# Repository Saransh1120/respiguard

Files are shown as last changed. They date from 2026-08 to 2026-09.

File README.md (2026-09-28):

# RespiGuard

A chest-worn asthma monitor built around an ESP32-S3. It learns the wearer's own
baseline for oxygen saturation, breathing rate and heart rate, then flags an
episode when those drift away from that baseline while a wheeze classifier is
also firing. Movement suppresses the alert, so exertion is not mistaken for an
attack.

Hand-soldered from breakout modules. The core modules cost about ₹2,674, or
about ₹3,503 with the optional BME680. Battery, power parts, enclosure and
assembly are extra. The separate ₹1,707 order in the hardware handbook covers
those power parts, the enclosure and bench tools, not the sensor modules.

## Where things stand

| | |
|---|---|
| Parts | Ordered 27 Aug 2026, awaiting delivery |
| Simulation | Working — reaches ALERT, exertion veto demonstrated |
| Self-test firmware | Written, compiles, untested on hardware |
| Real firmware | Written, compiles, untested on hardware |
| Recorder firmware | Written, compiles, untested on hardware |
| Wheeze model | Trained on ICBHI. AUC 0.747 |
| Enclosure | Modelled, STLs rendered, not printed |

Nothing in this project has run on real hardware yet. Everything compiles and
the model's export is verified against the trained network, but that is the
extent of it.

## What is where

| Folder | What it holds |
|---|---|
| `RespiGuard_selftest/` | Probes every sensor over raw I²C, prints a pass/fail table. Run this first. |
| `RespiGuard_firmware/` | The real firmware — detection logic, sensor drivers, the classifier. |
| `RespiGuard_recorder/` | Streams mic audio over USB, for collecting fine-tuning data. |
| `simulation/` | The Wokwi sketch and circuit the detection logic was proven in. |
| `enclosure/` | Parametric case in OpenSCAD, plus rendered STLs. |
| `docs/BRINGUP_GUIDE.html` | The assembly and test procedure. Open in a browser at the bench. |

The machine-learning work and the build tools sit on `D:`, deliberately outside
this OneDrive folder — the dataset is 1.8 GB and should not be syncing.

| Path | What it holds |
|---|---|
| `D:\respiguard-ml\` | Training pipeline, virtual environment, runs, results |
| `D:\datasets\icbhi\` | The ICBHI 2017 respiratory sound database |
| `D:\tools\arduino-cli\` | Compiles sketches without opening the IDE |
| `D:\tools\openscad\` | Renders the enclosure STLs |

## The order things happen in

**Now, before parts arrive.** Nothing left. Firmware, model, enclosure and the
bring-up procedure are all written.

**When parts arrive.** Follow `docs/BRINGUP_GUIDE.html`. Power first and alone,
then one sensor at a time with the self-test after each, then the real firmware.

**After that.** Record 50–100 normal breaths on the finished device with
`record.py`, fine-tune the classifier on them, re-export and re-verify. This is
the step that closes the gap between ICBHI's stethoscope recordings and a
microphone under clothing, and it is not optional.

## Rebuilding the model from scratch

    cd D:\respiguard-ml
    .venv\Scripts\python.exe prepare_icbhi.py --src D:\datasets\icbhi\extracted
    .venv\Scripts\python.exe train_wheeze.py --epochs 200 --lr 5e-4
    .venv\Scripts\python.exe export_weights.py
    .venv\Scripts\python.exe verify_export.py

`verify_export.py` is not a formality. It is what proves the header the firmware
compiles in computes the same thing as the network whose score you are quoting.
Run it after every export.

## On the numbers

The classifier scores AUC 0.747 on patients it never trained on. Sensitivity is
0.885 and specificity 0.391, at an operating point chosen to weight a missed
breath twice as heavily as a false alarm.

Those are ICBHI numbers — chest-contact stethoscope audio. The microphone on
this device sits under clothing. They are a ceiling to work down from, not a
prediction of what the device will do.

Similar products exist and are further along: Strados Labs' RESP biosensor and
Health Care Originals' ADAMM both do continuous wheeze detection, both with
clinical validation this project does not have. What is different here is the
price and that it is buildable by hand.

Validation against real patients runs through a clinician with written consent.
Until that happens it is future work, and should be described that way.

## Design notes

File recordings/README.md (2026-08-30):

# Hardware recordings

Normal breathing captured through the device's own INMP441 microphone. These
close the gap between the ICBHI stethoscope audio the classifier was trained on
and the sound the finished device actually hears through clothing.

Put files here with `record.py` from the machine-learning side:

    .venv\Scripts\python.exe record.py --label rest

It writes 30-second WAVs at 4 kHz mono. Copy them into the matching folder
below and push.

| Folder | What to record | How many |
|---|---|---|
| `rest/`  | sitting still | 20-30 |
| `walk/`  | walking | 15-20 |
| `stairs/`| climbing stairs | 15-20 |
| `sleep/` | lying down | 10-15 |

`stairs/` matters most. Climbing stairs raises breathing rate and heart rate
and drops SpO2 slightly, which looks a great deal like an episode. Without
those recordings the device alarms on every flight of stairs.

Every one of these is a **negative** example — breathing that is not an asthma
attack. Nobody needs to fake a wheeze. The wheezing examples come from ICBHI.

More people is better than more recordings from one person, since everyone
breathes differently.

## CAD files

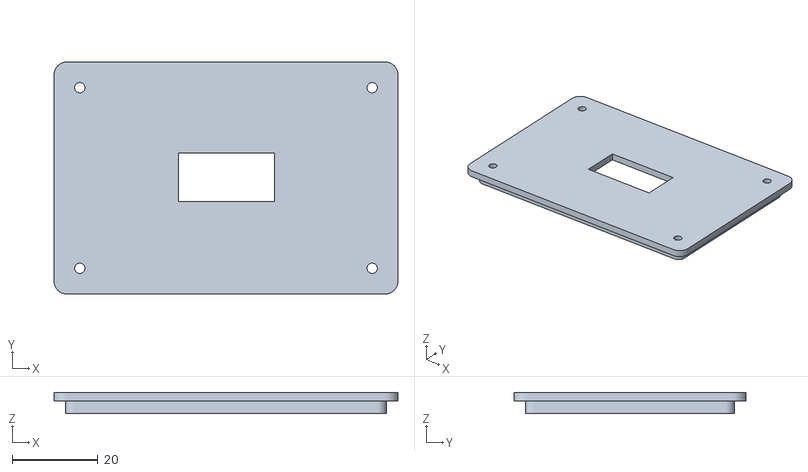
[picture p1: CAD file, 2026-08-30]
enclosure/lid.stl
80.0 x 54.0 x 4.99

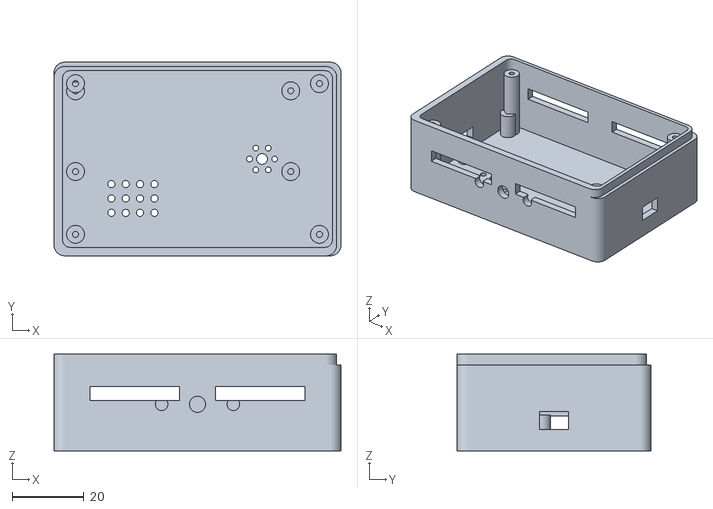
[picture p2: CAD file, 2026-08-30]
enclosure/base.stl
80.0 x 54.0 x 27.0

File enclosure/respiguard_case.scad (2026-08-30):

/*
  RespiGuard enclosure — 80 x 54 x 26 mm, two parts, FDM.

  Everything here is driven by the variables at the top. That is not tidiness
  for its own sake: none of the breakout boards have been measured yet, because
  they have not arrived. The numbers below are catalogue dimensions, and every
  one of them should be checked with calipers on the real part before anything
  is printed at full size. Changing one variable moves every feature that
  depends on it, so correcting a measurement is a one-line edit rather than a
  redesign.

  Two decisions are already settled and are built in rather than parameterised:

  USB-C sits on an end wall. The DevKitC-1 is 63 mm long with its USB on a short
  end, and the case is only 54 mm deep — the connector physically cannot face
  the front.

  The microphone port is on the base, facing the chest. Breath sounds travel
  better through the body than through air, so a port on the top edge would hear
  the room instead of the lungs.

  Printing:
    Material   PETG. PLA softens near 60 C and this is worn against a body and
               left in bags and on bikes.
    Layer      0.2 mm
    Walls      3 perimeters — the strap slots take real load
    Infill     20% gyroid
    Supports   none needed. Both halves print open-face down and every cutout is
               on a vertical wall or in the flat base.
    Orientation base: open side up. lid: outer face down.
*/

/* [Case] */
case_l = 80;      // length, USB end to end
case_w = 54;      // depth, chest to outside
case_h = 26;      // total height of the assembled case
wall   = 2.4;     // 3 perimeters at 0.4 mm nozzle, plus a little
floor_t = 2.0;
lid_t  = 2.0;
corner_r = 3;

/* [Fit] */
// FDM prints a fraction wider than nominal. Every opening and every mating
// surface is opened up by this much, which is the difference between a lid that
// closes and one that has to be filed.
clearance = 0.3;
lip_h = 3;        // depth of the lip that locates the lid
lip_t = 1.2;

/* [Boards — CHECK THESE WITH CALIPERS BEFORE PRINTING] */
esp_l = 63.0;   esp_w = 25.5;   esp_h = 4.5;    // DevKitC-1, without headers
oled_l = 27.0;  oled_w = 27.0;                  // 0.96" SSD1306 module
oled_screen_l = 22.0; oled_screen_w = 11.0;     // active glass, not the board
max_l = 20.5;   max_w = 15.5;                   // MAX30102 breakout
bme_l = 15.0;   bme_w = 13.0;                   // BME680 breakout
imu_l = 15.0;   imu_w = 13.0;                   // BMI270 breakout
mic_l = 17.0;   mic_w = 13.0;                   // INMP441 breakout
batt_l = 55.0;  batt_w = 34.0;  batt_h = 6.0;   // 1000 mAh Li-Po

/* [Openings] */
usbc_w = 9.5;   usbc_h = 4.0;                   // plus clearance, applied below
button_d = 4.2;
led_d = 3.2;
mic_port_d = 3.0;
vent_d = 2.0;                                   // BME680 needs outside air

/* [Fasteners] */
boss_od = 5.0;
boss_id = 1.7;    // M2 self-tapping into plastic
boss_h  = 4.0;

$fn = 48;

// ---------------------------------------------------------------- helpers

module rrect(l, w, h, r) {
  hull() for (x = [r, l - r], y = [r, w - r])
    translate([x, y, 0]) cylinder(r = r, h = h);
}

/* A screw boss: post with a pilot hole down the middle. */
module boss(h = boss_h) {
  difference() {
    cylinder(d = boss_od, h = h);
    translate([0, 0, -0.1]) cylinder(d = boss_id, h = h + 0.2);
  }
}

/* Standoff that lifts a board off the floor and takes a screw. */
module standoff(h) {
  difference() {
    cylinder(d = boss_od, h = h);
    translate([0, 0, 1]) cylinder(d = boss_id, h = h);
  }
}

// ---------------------------------------------------------------- base

module base() {
  difference() {
    union() {
      // Outer shell.
      rrect(case_l, case_w, case_h - lid_t, corner_r);

      // Locating lip, standing proud of the wall top for the lid to sit over.
      translate([0, 0, case_h - lid_t])
        difference() {
          rrect(case_l - wall + lip_t, case_w - wall + lip_t, lip_h, corner_r);
          translate([wall, wall, -0.1])
            rrect(case_l - 2 * wall, case_w - 2 * wall, lip_h + 0.2, corner_r - 1);
        }
    }

    // Hollow it out.
    translate([wall, wall, floor_t])
      rrect(case_l - 2 * wall, case_w - 2 * wall, case_h, corner_r - 1);

    // --- USB-C, on the end wall ---
    // Positioned against the ESP32's own board height above the floor, so the
    // hole lines up with the connector rather than with the middle of the wall.
    translate([-1, case_w / 2 - (usbc_w + clearance) / 2, floor_t + 3.5])
      cube([wall + 2, usbc_w + clearance, usbc_h + clearance]);

    // --- microphone port, in the base, facing the chest ---
    // A ring of small holes rather than one large one: it passes sound just as
    // well, keeps fabric and dust out, and does not need a support.
    translate([case_l - 22, case_w / 2, -0.1]) {
      cylinder(d = mic_port_d, h = floor_t + 0.2);
      for (a = [0 : 60 : 300])
        rotate([0, 0, a]) translate([3.5, 0, 0])
          cylinder(d = 1.6, h = floor_t + 0.2);
    }

    // --- BME680 vents, in the base ---
    // The gas sensor reads the air it sits in. Sealed inside a box it measures
    // the box.
    translate([16, 12, -0.1])
      for (x = [0 : 4 : 12], y = [0 : 4 : 8])
        translate([x, y, 0]) cylinder(d = vent_d, h = floor_t + 0.2);

    // --- button, on the front wall ---
    translate([case_l / 2, -1, case_h / 2])
      rotate([-90, 0, 0]) cylinder(d = button_d + clearance, h = wall + 2);

    // --- LEDs, on the front wall ---
    for (x = [case_l / 2 - 10, case_l / 2 + 10])
      translate([x, -1, case_h / 2])
        rotate([-90, 0, 0]) cylinder(d = led_d + clearance, h = wall + 2);

    // --- slide switch, on the end wall opposite USB ---
    translate([case_l - wall - 1, case_w / 2 - 4, floor_t + 4])
      cube([wall + 2, 8, 5]);

    // --- strap slots ---
    // Through the side walls, wide enough for a 25 mm chest strap.
    for (x = [10, case_l - 10 - 25])
      for (y = [-1, case_w - wall - 1])
        translate([x, y, case_h - lid_t - 10])
          cube([25, wall + 2, 4]);
  }

  // --- interior standoffs ---
  // The battery lies flat in the floor; boards sit above it on these.
  esp_x = 6; esp_y = case_w - esp_w - 5;
  for (p = [[esp_x, esp_y], [esp_x + esp_l - 3, esp_y],
            [esp_x, esp_y + esp_w - 3], [esp_x + esp_l - 3, esp_y + esp_w - 3]])
    translate([p[0], p[1], floor_t]) standoff(batt_h + 2);

  // Corner bosses for the lid screws.
  for (p = [[6, 6], [case_l - 6, 6], [6, case_w - 6], [case_l - 6, case_w - 6]])
    translate([p[0], p[1], floor_t]) boss(case_h - lid_t - floor_t);
}

// ---------------------------------------------------------------- lid

module lid() {
  difference() {
    rrect(case_l, case_w, lid_t, corner_r);

    // --- OLED window ---
    // Cut to the active glass, not the module outline: the board is 27 mm
    // square but only a strip of it lights up, and a window the size of the
    // board looks like a mistake.
    translate([case_l / 2 - oled_screen_l / 2,
               case_w / 2 - oled_screen_w / 2, -0.1])
      cube([oled_screen_l + clearance, oled_screen_w + clearance, lid_t + 0.2]);

    // Screw holes, clearance not pilot — the thread bites in the base.
    for (p = [[6, 6], [case_l - 6, 6], [6, case_w - 6], [case_l - 6, case_w - 6]])
      translate([p[0], p[1], -0.1]) cylinder(d = 2.4, h = lid_t + 0.2);
  }

  // Inner rib, so the lid locates on the base lip instead of sliding around.
  translate([0, 0, -lip_h + 0.01])
    difference() {
      translate([wall + clearance, wall + clearance, 0])
        rrect(case_l - 2 * (wall + clearance), case_w - 2 * (wall + clearance),
              lip_h, corner_r - 1);
      translate([wall + lip_t + clearance, wall + lip_t + clearance, -0.1])
        rrect(case_l - 2 * (wall + lip_t + clearance),
              case_w - 2 * (wall + lip_t + clearance), lip_h + 0.2, corner_r - 1);
    }
}

// ---------------------------------------------------------------- output

// Render one at a time. Set part to "base", "lid", or "both".
part = "both";

if (part == "base") base();
else if (part == "lid") lid();
else {
  base();
  translate([0, case_w + 10, 0]) lid();
}

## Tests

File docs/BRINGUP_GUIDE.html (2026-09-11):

Workbench procedure

# Bringing RespiGuard up, one part at a time

Thirty-five components, six breakout boards and a battery, assembled by hand. The order below is not a preference — it is the order in which a mistake stays cheap. Every step ends with something you must see before the next one begins.

Board ESP32-S3-DevKitC-1 Self-test RespiGuard_selftest.ino Serial 115200 baud

## The rule this whole procedure rests on

Add one part. Test it. Only then add the next. Soldering everything and powering up once is how a build reaches a state where nothing works and there are six possible reasons why. Every fault you meet here should have exactly one candidate cause: the thing you just attached.

Phase 0

## Before the iron is even hot

Two of the parts that arrive can be the wrong part while carrying the right name. Both are cheaper to catch now than after they are soldered down.

01

### Count the chips on the TP4056

Look at the charger board under a light. You need three black chips: the TP4056 itself, a DW01 and an FS8205. Boards with only the TP4056 are sold under the same name and the same photo.

Reject A single-chip board has no over-discharge protection. It will run the Li-Po flat past 2.5 V and permanently kill the cell — quietly, over one long night.

02

### Confirm the ESP32 board has PSRAM

The wheeze classifier asks for 234 KB of working memory at startup. A compile of the finished firmware leaves only 185 KB of internal RAM free, so that allocation has to land in PSRAM.

Look for N8R8 or N16R8 in the board's markings — the R8 is the PSRAM.

If absent The firmware still runs, but classifier.begin() returns false and the serial banner prints model FAILED. Wheeze detection is then dead and the score loses its heaviest term.

Phase 1

## Power, with nothing else connected

Power comes first and alone. A rail set wrong with the ESP32 already attached destroys the most expensive part on the bench in the time it takes to notice.

03

### Set the buck-boost to 3.3 V before it touches anything

Feed the module from the battery or a USB supply. Put the multimeter on its output, turn the trimmer, and bring it to 3.30 V. Nothing else is wired at this point.

Confirm Multimeter reads between 3.25 and 3.35 V, steady, with the supply moving.

Why alone These modules ship set anywhere from 1 V to 12 V. Wiring first and adjusting after puts whatever it happened to be set to straight across a 3.3 V part.

04

### Battery, switch and charger

Li-Po into the TP4056 through the JST connector. The SPDT slide switch goes between the charger's output and the buck-boost input, so it cuts the battery and not the charging path.

Confirm Switch on gives 3.3 V at the buck-boost output; switch off gives 0 V. Plugging USB into the TP4056 lights its charge LED with the switch in either position.

05

### Decoupling capacitors

The 470 µF electrolytic goes across the 3.3 V rail close to the buck-boost — mind the polarity stripe. A 100 nF ceramic goes next to each of the four breakout boards' power pins.

Confirm Rail still reads 3.3 V, and continuity between the 470 µF terminals reads open, not a short.

Phase 2

## The ESP32 alone

Before any sensor, prove the board itself and the one analogue circuit that is easy to get wrong.

06

### Blink, over USB only

Board still off the battery rail. Flash anything that toggles a pin and confirm the Arduino IDE can talk to it.

Confirm Sketch uploads, and the serial monitor shows output at 115200.

07

### Battery divider on GPIO 1

Two 100 kΩ resistors in series across the battery, with GPIO 1 at their junction. The firmware reads that pin and doubles it.

Confirm The voltage the firmware prints matches what the multimeter reads across the cell, within about 0.1 V.

Phase 3

## I²C, one device per test

All four I²C parts share two wires — SDA 8 and SCL 9. Attach them one at a time and run RespiGuard_selftest.ino after each. It probes every address and prints a pass/fail table, and it needs no libraries.

Part | Address | ID register | Expected
SSD1306 OLED | 0x3C | — | draws
MAX30102 | 0x57 | 0xFF | 0x15
BME680 | 0x76 / 0x77 | 0xD0 | 0x61
BMI270 | 0x68 / 0x69 | 0x00 | 0x24

08

### OLED first, because it proves the bus

The display is the one I²C part whose success is visible without reading a number. If it draws, SDA, SCL, power and ground are all correct, and every later failure belongs to the part being added rather than to the wiring underneath it.

Confirm Self-test reports 0x3C found, and something appears on the screen.

09

### MAX30102

Register 0xFF must return 0x15. With a finger on it, the red LED should be faintly visible through the skin.

Confirm 0x57 answers and the part ID reads 0x15.

10

### BME680 — and the substitution to watch for

Register 0xD0 must return 0x61.

If 0x58 You have a BMP280 sold as a BME680. It is a common substitution. Pressure and temperature will work; the gas sensor does not exist on that die. Return it.

11

### BMI270

Register 0x00 must return 0x24. This part needs an 8 KB configuration blob uploaded at every power-on before it produces data, which is why the firmware drives it through the SparkFun library rather than raw I²C like the others.

Confirm ID reads 0x24, and tilting the board changes the acceleration values.

Phase 4

## The microphone

The INMP441 is on I²S, not I²C, so nothing in the self-test table covers it. It is also the part the whole wheeze track depends on.

12

### INMP441, with L/R tied to ground

Wire BCLK 4, WS 5, SD 6. The board's L/R pin must go to ground: the firmware opens the port as ONLY_LEFT, and a mic left on the right channel returns a buffer of zeros with no error anywhere.

Confirm Print the raw I²S samples. Silence should still show small non-zero values that jump when you speak. A perfectly flat zero means the channel is wrong, not that the room is quiet.

13

### Mount it facing the chest, on the base

Breath sounds travel better through the body than through air. The mic port goes on the underside of the enclosure, against the skin — not on the top edge where it would mostly hear the room.

Phase 5

## Outputs and the button

The cheapest parts, and the last, because none of them can hide a fault in anything else.

14

### LEDs

Green on 15, red on 16, each through a 220 Ω resistor to ground.

15

### Vibration motor — the diode is not optional

GPIO 17 through 1 kΩ into the base of the 2N2222; motor between the collector and 3.3 V; emitter to ground.

Flyback The 1N4148 goes across the motor terminals, banded end to the positive side. Without it, every switch-off sends an inductive spike back into the transistor and onto the rail — which shows up later as an ESP32 that resets at random and looks like a firmware bug.

16

### Button on GPIO 18

One side to the pin, the other to ground. No pull-up resistor — the pin is configured INPUT_PULLUP in firmware.

Confirm Short press marks an event and buzzes once; holding 1.5 s clears the baseline and restarts learning.

Phase 6

## The real firmware

17

### Flash RespiGuard_firmware and read the banner

The sketch prints a startup summary. All six lines have to be good before anything else is worth debugging.

Line | Must say | If not
MAX30102 | found | Back to step 09
BMI270 | found | Back to step 11
BME680 | found | Back to step 10
INMP441 | started | Back to step 12
model | loaded | No PSRAM — step 02
battery | a real voltage | Back to step 07

Fix this before flashing In wheeze.h the audio front end is still set to 16 kHz (WZ_SAMPLE_RATE 16000, N_FFT 512, hop 256). The model was trained in prepare_icbhi.py at 4 kHz with N_FFT 256 and hop 64. Change the constants in wheeze.h to match the training script exactly (check the mel band limits too) and recompile. With the mismatch in place the model does not crash; it just returns confident numbers that mean nothing.

Expect trouble This firmware has never run on hardware. It compiles clean and its maths is verified against the trained model, but nothing more. Bugs at this step are the normal outcome, not a sign something is wrong with the build.

Phase 7

## Teaching the classifier what your hardware sounds like

The model was trained on ICBHI — a chest-contact stethoscope. Your microphone sits under clothing. That gap is the largest single risk in the project, and this phase is what closes it.

18

### Record 50–100 normal breaths on the finished device

Worn as it will actually be worn: strap on, clothing over it, sitting and walking. Normal breathing only, which raises no ethics question because it is the negative class.

Tools are ready Flash RespiGuard_recorder. It streams raw microphone audio over USB at 4 kHz. On the laptop, run record.py from D:\respiguard-ml\ to save each recording as a WAV file.

19

### Fine-tune, re-export, re-verify

Continue training from the ICBHI weights with those recordings mixed in, then run export_weights.py and verify_export.py. The second one is not a formality: it is what proves the header the firmware compiles in computes the same thing the network you just measured computes.

Confirm verify_export.py prints PASS, and the firmware still compiles with the new weights.

20

### Wear it for three days

The baseline window is three days on hardware, not the twenty seconds the simulation used. Until that window closes the device shows LEARNING and will not raise a state — it has no personal baseline to deviate from yet.

## What this procedure does not give you

Finishing every step above gets you a device that detects wheeze on your own hardware and scores it against your own baseline. It does not get you a validated medical instrument, and the difference matters when describing the project.

Validation against real patients runs through a clinician, with written consent, and is a separate piece of work. Until that happens it belongs in any write-up as future work — never as something already done.

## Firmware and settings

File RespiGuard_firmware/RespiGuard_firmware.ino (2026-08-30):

/*
  RespiGuard — hardware firmware.

  This is wokwi_sketch.txt with the simulation removed. The detection logic
  below — baseline learning, deviation scoring, the exertion veto, the state
  machine, the display and the button — is character-for-character the logic
  that was proven in simulation. It was ported by replacing sampleSensors()
  and nothing else, which was the plan from the start.

  What is now real:
    MAX30102   SpO2, heart rate and respiratory rate      (max30102.h)
    INMP441    wheeze, via log-mel and the trained model  (wheeze.h)
    BMI270     movement, for the exertion veto
    BME680     air quality
    SSD1306    display

  Two differences from the simulation, both deliberate:

  The baseline window is three days, not twenty seconds. A personal baseline
  built over twenty seconds is whatever the wearer happened to be doing during
  those twenty seconds. Three days covers sleep, rest and exertion.

  A vital that cannot be measured is dropped, not guessed. If the optical
  sensor loses chest contact, sampleSensors() leaves the previous value in
  place and marks the sample stale rather than feeding a number computed from
  ambient light into the baseline. A monitor that invents readings when it
  cannot see is worse than one that says nothing.

  Libraries: Adafruit SSD1306, Adafruit GFX, Adafruit BME680, SparkFun BMI270.

  The classifier deliberately needs no machine-learning library. Its weights are
  compiled in from wheeze_model.h and its forward pass is in classifier.h, which
  is less code than the interpreter would have been and leaves the arithmetic on
  the device open to inspection.
*/

#include <Wire.h>
#include <Adafruit_GFX.h>
#include <Adafruit_SSD1306.h>
#include <Adafruit_BME680.h>
#include <SparkFun_BMI270_Arduino_Library.h>

#include "max30102.h"
#include "wheeze.h"
#include "classifier.h"

// ------------------------------------------------------------------ pins
#define PIN_SDA        8
#define PIN_SCL        9
#define PIN_LED_GREEN  15
#define PIN_LED_RED    16
#define PIN_MOTOR      17
#define PIN_BUTTON     18
#define PIN_BATTERY    1

#define OLED_W 128
#define OLED_H 64
Adafruit_SSD1306 display(OLED_W, OLED_H, &Wire, -1);
Adafruit_BME680  bme;
BMI270           imu;
MAX30102         ppg;
WheezeFrontEnd   mic;
WheezeClassifier classifier;

// -------------------------------------------------------------- tuning
// Every threshold here is a deviation from the wearer's own baseline, not an
// absolute number. Asthma presents differently in every person, so a fixed
// "SpO2 below 94" rule produces constant false alarms in some people and
// misses real attacks in others.
const uint32_t BASELINE_SECONDS   = 3UL * 24 * 3600;  // three days
const float    RR_RISE_FRAC       = 0.20;
const float    HR_RISE_FRAC       = 0.15;
const float    SPO2_DROP_POINTS   = 3.0;
const float    WHEEZE_THRESHOLD   = 0.50;
const float    ACTIVITY_VETO      = 0.35;

const int   SCORE_WATCH = 2;
const int   SCORE_ALERT = 4;
const uint32_t ALERT_HOLD_MS = 4000;

// -------------------------------------------------------------- state
enum State { STATE_LEARNING, STATE_OK, STATE_WATCH, STATE_ALERT };
State state = STATE_LEARNING;

const char *stateName();

struct Vitals {
  float spo2;
  float rr;
  float hr;
  float wheeze;
  float activity;
  float voc;
};

Vitals now;
bool   vitalsValid = false;   // false while the optical sensor has no contact

double baseSpo2 = 0, baseRr = 0, baseHr = 0;
uint32_t baseCount = 0;
bool baselineReady = false;

uint32_t lastSample = 0;
uint32_t stateEnteredAt = 0;
uint32_t lastBuzz = 0;
uint32_t eventsMarked = 0;
int lastScore = 0;
char lastReason[24] = "";

bool bmePresent = false, imuPresent = false;

// ------------------------------------------------------------- BMI270
/*
  Distance of the acceleration magnitude from 1 g, smoothed.

  Identical maths to the MPU6050 stand-in used in simulation; only the driver
  underneath changed. The BMI270 needs an 8 KB configuration blob uploaded at
  power-on before it will produce data at all, which is why this one sensor
  uses a library rather than raw I2C like the others.
*/
float imuActivity() {
  if (!imuPresent) return 0.0f;
  imu.getSensorData();

  float x = imu.data.accelX, y = imu.data.accelY, z = imu.data.accelZ;
  float mag = sqrtf(x * x + y * y + z * z);
  float dev = fabsf(mag - 1.0f);

  static float smooth = 0;
  smooth = smooth * 0.7f + dev * 0.3f;
  return constrain(smooth, 0.0f, 1.0f);
}

// ------------------------------------------------------- real sensors
/*
  The one function the port was supposed to touch.

  Each vital is taken from the part that actually measures it. Where a reading
  cannot be trusted the previous value stands and `vitalsValid` goes false, so
  the baseline never absorbs a number the hardware did not really see.
*/
void sampleSensors() {
  // Wheeze first: the classifier runs on four seconds of audio that the front
  // end has been accumulating in the background since the last call.
  if (mic.ready()) {
    static float patch[WZ_N_MELS * WZ_FRAMES];
    if (mic.patch(patch)) now.wheeze = classifier.predict(patch);
  } else {
    now.wheeze = 0.0f;
  }

  now.activity = imuActivity();

  if (bmePresent && bme.performReading()) {
    now.voc = bme.gas_resistance / 1000.0f;   // kOhm
  }

  // The optical sensor. Without contact the ratio-of-ratios is computed out of
  // ambient light and returns a confident, meaningless number.
  if (!ppg.present() || !ppg.contact() || !ppg.ready()) {
    vitalsValid = false;
    return;
  }

  float s = ppg.spo2();
  float h = ppg.heartRate();
  float r = ppg.respiratoryRate();

  // A single NaN means that one estimator failed this second — the finger
  // moved, the window straddled a motion artefact. Keeping the last good value
  // is right; treating the whole sample as valid when a vital is missing is not.
  bool ok = !isnan(s) && !isnan(h) && !isnan(r);
  if (!isnan(s)) now.spo2 = s;
  if (!isnan(h)) now.hr   = h;
  if (!isnan(r)) now.rr   = r;
  vitalsValid = ok;
}

// ----------------------------------------------------------- baseline
void updateBaseline() {
  // Only real readings shape the personal baseline.
  if (!vitalsValid) return;

  baseSpo2 += now.spo2;
  baseRr   += now.rr;
  baseHr   += now.hr;
  baseCount++;

  if (baseCount >= BASELINE_SECONDS) {
    baseSpo2 /= baseCount;
    baseRr   /= baseCount;
    baseHr   /= baseCount;
    baselineReady = true;
    state = STATE_OK;
    stateEnteredAt = millis();

    Serial.println();
    Serial.println("  baseline learned:");
    Serial.printf("    SpO2 %.1f %%   RR %.1f /min   HR %.0f bpm\n",
                  baseSpo2, baseRr, baseHr);
    Serial.println("  monitoring now.");
    Serial.println();
  }
}

void resetBaseline() {
  baseSpo2 = baseRr = baseHr = 0;
  baseCount = 0;
  baselineReady = false;
  state = STATE_LEARNING;
  stateEnteredAt = millis();
  lastReason[0] = 0;
  Serial.println("  baseline cleared, relearning");
}

// -------------------------------------------------------------- scoring
int scoreDeviation() {
  int score = 0;
  lastReason[0] = 0;

  bool rrHigh    = now.rr   > baseRr * (1.0f + RR_RISE_FRAC);
  bool hrHigh    = now.hr   > baseHr * (1.0f + HR_RISE_FRAC);
  bool spo2Low   = now.spo2 < baseSpo2 - SPO2_DROP_POINTS;
  bool wheezing  = now.wheeze > WHEEZE_THRESHOLD;

  // Wheeze and desaturation carry more weight because neither is explained by
  // ordinary activity. Rate changes alone are weak evidence.
  if (wheezing) { score += 2; strncpy(lastReason, "wheeze", sizeof(lastReason)); }
  if (spo2Low)  { score += 2; strncpy(lastReason, "SpO2 drop", sizeof(lastReason)); }
  if (rrHigh)   { score += 1; if (!lastReason[0]) strncpy(lastReason, "RR rise", sizeof(lastReason)); }
  if (hrHigh)   { score += 1; if (!lastReason[0]) strncpy(lastReason, "HR rise", sizeof(lastReason)); }

  // The exertion veto. Running up stairs raises RR and HR and drops SpO2 a
  // little; without this the device would alarm on every PE class.
  if (now.activity > ACTIVITY_VETO && !wheezing) {
    score -= 2;
    strncpy(lastReason, "moving", sizeof(lastReason));
  }

  return max(score, 0);
}

void updateState() {
  if (!baselineReady) return;

  // Scoring a stale sample would compare the baseline against numbers from
  // whenever contact was last good, which could be minutes ago.
  if (!vitalsValid) return;

  int score = scoreDeviation();
  lastScore = score;

  State target;
  if (score >= SCORE_ALERT)      target = STATE_ALERT;
  else if (score >= SCORE_WATCH) target = STATE_WATCH;
  else                           target = STATE_OK;

  bool calming = target < state;
  if (calming && millis() - stateEnteredAt < ALERT_HOLD_MS) return;

  if (target != state) {
    state = target;
    stateEnteredAt = millis();
    Serial.printf("  -> %s  (score %d, %s)\n", stateName(), score,
                  lastReason[0] ? lastReason : "within baseline");
  }
}

const char *stateName() {
  switch (state) {
    case STATE_LEARNING: return "LEARNING";
    case STATE_OK:       return "OK";
    case STATE_WATCH:    return "WATCH";
    default:             return "ALERT";
  }
}

// --------------------------------------------------------------- battery
/* Two 100 k resistors halve the cell voltage into the ADC. */
float batteryVolts() {
  return analogReadMilliVolts(PIN_BATTERY) * 2.0f / 1000.0f;
}

// ------------------------------------------------------------- outputs
void driveOutputs() {
  bool alert = (state == STATE_ALERT);
  bool watch = (state == STATE_WATCH);

  digitalWrite(PIN_LED_GREEN, state == STATE_OK);

  if (alert) {
    digitalWrite(PIN_LED_RED, (millis() / 250) % 2);
  } else if (watch) {
    digitalWrite(PIN_LED_RED, (millis() / 800) % 2);
  } else {
    digitalWrite(PIN_LED_RED, LOW);
  }

  // Haptic: a double pulse every four seconds while in alert. The delays here
  // are short enough not to starve the audio front end of a hop.
  if (alert && millis() - lastBuzz > 4000) {
    lastBuzz = millis();
    for (int i = 0; i < 2; i++) {
      digitalWrite(PIN_MOTOR, HIGH); delay(120);
      digitalWrite(PIN_MOTOR, LOW);  delay(100);
    }
  }
}

void drawScreen() {
  display.clearDisplay();
  display.setTextColor(SSD1306_WHITE);

  display.setTextSize(1);
  display.setCursor(0, 0);
  display.print("RespiGuard");

  const char *s = stateName();
  int w = strlen(s) * 6;
  if (state == STATE_ALERT || state == STATE_WATCH) {
    display.fillRect(OLED_W - w - 4, 0, w + 4, 9, SSD1306_WHITE);
    display.setTextColor(SSD1306_BLACK);
  }
  display.setCursor(OLED_W - w - 2, 1);
  display.print(s);
  display.setTextColor(SSD1306_WHITE);
  display.drawFastHLine(0, 11, OLED_W, SSD1306_WHITE);

  if (!vitalsValid && state != STATE_LEARNING) {
    // Saying so is the honest screen. A frozen set of numbers with no notice
    // reads as a working device.
    display.setCursor(0, 24);
    display.print("No chest contact");
    display.setCursor(0, 36);
    display.print("readings paused");
    display.display();
    return;
  }

  if (state == STATE_LEARNING) {
    display.setCursor(0, 16);
    display.print("Learning baseline");
    // Three days in seconds is not a number that reads well, so show hours.
    display.setCursor(0, 28);
    display.printf("%lu / %lu h", (unsigned long)(baseCount / 3600),
                   (unsigned long)(BASELINE_SECONDS / 3600));
    int barW = (int)((float)baseCount / BASELINE_SECONDS * (OLED_W - 4));
    display.drawRect(0, 42, OLED_W, 10, SSD1306_WHITE);
    display.fillRect(2, 44, constrain(barW, 0, OLED_W - 4), 6, SSD1306_WHITE);
    display.setCursor(0, 56);
    display.printf("WZ %.2f  %.2fV", now.wheeze, batteryVolts());
  } else {
    display.setCursor(0, 16);
    display.printf("SpO2 %4.1f%%  b%4.1f", now.spo2, baseSpo2);
    display.setCursor(0, 26);
    display.printf("RR   %4.1f    b%4.1f", now.rr, baseRr);
    display.setCursor(0, 36);
    display.printf("HR   %4.0f    b%4.0f", now.hr, baseHr);
    display.setCursor(0, 46);
    display.printf("WZ %.2f  ACT %.2f", now.wheeze, now.activity);

    display.setCursor(0, 56);
    if (lastReason[0]) display.printf("%s  score %d", lastReason, lastScore);
    else               display.printf("within baseline");
  }

  display.display();
}

// -------------------------------------------------------------- button
void handleButton() {
  static bool wasDown = false;
  static uint32_t downAt = 0;

  bool down = (digitalRead(PIN_BUTTON) == LOW);

  if (down && !wasDown) {
    downAt = millis();
  } else if (!down && wasDown) {
    uint32_t held = millis() - downAt;
    if (held > 1500) {
      resetBaseline();
    } else if (held > 30) {
      eventsMarked++;
      Serial.printf("  event %lu marked by wearer\n", (unsigned long)eventsMarked);
      digitalWrite(PIN_MOTOR, HIGH); delay(80); digitalWrite(PIN_MOTOR, LOW);
    }
  }
  wasDown = down;
}

// --------------------------------------------------------------- setup
void setup() {
  Serial.begin(115200);
  delay(200);

  pinMode(PIN_LED_GREEN, OUTPUT);
  pinMode(PIN_LED_RED, OUTPUT);
  pinMode(PIN_MOTOR, OUTPUT);
  pinMode(PIN_BUTTON, INPUT_PULLUP);

  Wire.begin(PIN_SDA, PIN_SCL);
  Wire.setClock(400000);

  if (!display.begin(SSD1306_SWITCHCAPVCC, 0x3C)) {
    Serial.println("  OLED not found at 0x3C");
  }
  display.clearDisplay();
  display.display();

  bool ppgOk = ppg.begin();
  imuPresent = (imu.beginI2C(0x68) == BMI2_OK) || (imu.beginI2C(0x69) == BMI2_OK);
  bmePresent = bme.begin(0x76) || bme.begin(0x77);
  if (bmePresent) {
    bme.setGasHeater(320, 150);   // 320 C for 150 ms
  }
  bool micOk = mic.begin();
  bool modelOk = classifier.begin();

  Serial.println();
  Serial.println("========================================");
  Serial.println("  RespiGuard - hardware");
  Serial.println("========================================");
  Serial.printf("  MAX30102  %s\n", ppgOk      ? "found" : "MISSING");
  Serial.printf("  BMI270    %s\n", imuPresent ? "found" : "MISSING");
  Serial.printf("  BME680    %s\n", bmePresent ? "found" : "MISSING");
  Serial.printf("  INMP441   %s\n", micOk      ? "started" : "FAILED");
  Serial.printf("  model     %s\n", modelOk    ? "loaded" : "FAILED");
  Serial.printf("  battery   %.2f V\n", batteryVolts());
  Serial.printf("  learning baseline for %lu h\n",
                (unsigned long)(BASELINE_SECONDS / 3600));
  Serial.println("  short press = mark event, hold 1.5 s = relearn");
  Serial.println();

  stateEnteredAt = millis();
}

void loop() {
  handleButton();

  // Both of these must run far more often than once a second. The optical FIFO
  // holds only 32 samples — a third of a second at 100 Hz — and the audio front
  // end needs a hop taken every 16 ms or the I2S DMA buffers overrun.
  ppg.poll();
  mic.poll();

  if (millis() - lastSample >= 1000) {
    lastSample = millis();

    sampleSensors();
    if (!baselineReady) updateBaseline();
    else                updateState();

    Serial.printf("  SpO2 %5.1f  RR %5.1f  HR %5.0f  WZ %.2f  ACT %.2f  [%s]%s\n",
                  now.spo2, now.rr, now.hr, now.wheeze, now.activity, stateName(),
                  vitalsValid ? "" : "  (no contact)");
  }

  driveOutputs();

  // The screen is the slowest thing on the I2C bus. Redrawing it every pass
  // starves the sensor polling above, so it gets its own cadence.
  static uint32_t lastDraw = 0;
  if (millis() - lastDraw >= 250) {
    lastDraw = millis();
    drawScreen();
  }
}

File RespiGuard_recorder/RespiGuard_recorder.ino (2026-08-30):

/*
  RespiGuard — recording sketch.

  Streams raw microphone audio over USB so that normal breathing can be captured
  on the finished device and used to fine-tune the wheeze classifier. This is the
  one piece of the machine-learning plan that cannot be done without hardware:
  the model was trained on a stethoscope pressed to the chest, and the INMP441
  sits under clothing. Recordings made here are what close that gap.

  Only the negative class is collected — ordinary breathing, from whoever is
  wearing it. That raises no ethics question and needs no consent process, which
  is exactly why it is the half of the problem worth solving first.

  The audio is sent at 4 kHz, matching prepare_icbhi.py, so the recordings drop
  straight into the training set without resampling. A 16-bit sample at 4 kHz is
  64 kbit/s, comfortably inside the serial link, so nothing has to be compressed
  or buffered to an SD card.

  Wiring is the same as the main firmware: BCLK 4, WS 5, SD 6, and the mic's L/R
  pin to ground.

  Use:
    1. Flash this sketch.
    2. Close the Arduino serial monitor — it will hold the port otherwise.
    3. Run  python record.py --seconds 30 --label rest
    4. Press the button, or just start the script; recording runs until it stops.
*/

#include <driver/i2s.h>

#define PIN_I2S_BCLK 4
#define PIN_I2S_WS   5
#define PIN_I2S_SD   6
#define PIN_LED_RED  16
#define PIN_BUTTON   18

// Matches prepare_icbhi.py. Recording at the training rate means the captured
// audio needs no resampling later, and resampling is a step where a quiet
// mismatch with the training features could creep in.
static const int SAMPLE_RATE = 4000;
static const int CHUNK = 256;

// A short header on every chunk. Without it, a byte dropped on the wire would
// shift every following sample by one and turn the recording into noise that
// still looks like audio.
static const uint8_t MAGIC[4] = {0x52, 0x47, 0x41, 0x31};   // "RGA1"

void setup() {
  // The bit rate here is for the USB CDC link, not the audio. It is set high so
  // the serial link is never the bottleneck.
  Serial.begin(921600);
  pinMode(PIN_LED_RED, OUTPUT);
  pinMode(PIN_BUTTON, INPUT_PULLUP);

  i2s_config_t cfg = {};
  cfg.mode = (i2s_mode_t)(I2S_MODE_MASTER | I2S_MODE_RX);
  cfg.sample_rate = SAMPLE_RATE;
  // The INMP441 places a 24-bit sample inside a 32-bit slot. Reading 32 and
  // shifting down is correct; reading 16 takes the wrong end of the word and
  // returns something that looks like noise but is not.
  cfg.bits_per_sample = I2S_BITS_PER_SAMPLE_32BIT;
  cfg.channel_format = I2S_CHANNEL_FMT_ONLY_LEFT;
  cfg.communication_format = I2S_COMM_FORMAT_STAND_I2S;
  cfg.intr_alloc_flags = ESP_INTR_FLAG_LEVEL1;
  cfg.dma_buf_count = 8;
  cfg.dma_buf_len = CHUNK;
  cfg.use_apll = false;

  i2s_pin_config_t pins = {};
  pins.bck_io_num = PIN_I2S_BCLK;
  pins.ws_io_num = PIN_I2S_WS;
  pins.data_out_num = I2S_PIN_NO_CHANGE;
  pins.data_in_num = PIN_I2S_SD;

  if (i2s_driver_install(I2S_NUM_0, &cfg, 0, NULL) != ESP_OK ||
      i2s_set_pin(I2S_NUM_0, &pins) != ESP_OK) {
    // Fast blink forever: the host script will see no data and this says why.
    while (true) {
      digitalWrite(PIN_LED_RED, !digitalRead(PIN_LED_RED));
      delay(100);
    }
  }
}

void loop() {
  static int32_t raw[CHUNK];
  static int16_t out[CHUNK];

  size_t bytesRead = 0;
  if (i2s_read(I2S_NUM_0, raw, sizeof(raw), &bytesRead, portMAX_DELAY) != ESP_OK) return;
  int got = bytesRead / sizeof(int32_t);
  if (got <= 0) return;

  // 24-bit sample sitting in the top of a 32-bit word, brought down to 16 bits.
  // The shift is 16 rather than 8 because the low byte of the 24 is below the
  // mic's own noise floor and carries nothing.
  for (int i = 0; i < got; i++) out[i] = (int16_t)(raw[i] >> 16);

  Serial.write(MAGIC, 4);
  uint16_t n = got;
  Serial.write((uint8_t *)&n, 2);
  Serial.write((uint8_t *)out, got * sizeof(int16_t));

  // Slow heartbeat, so it is obvious at a glance that audio is still flowing.
  digitalWrite(PIN_LED_RED, (millis() / 500) % 2);
}

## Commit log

2026-08-30 RespiGuard: firmware, simulation, enclosure and bring-up guide
    Chest-worn asthma monitor on an ESP32-S3. Detection runs against the
    wearer's own learned baseline rather than fixed thresholds, with an
    exertion veto so movement is not mistaken for an episode.
    Contents:
    RespiGuard_selftest probes every sensor over raw I2C, no libraries
    RespiGuard_firmware the real firmware, written but not yet run
    RespiGuard_recorder streams mic audio over USB for fine-tuning
    simulation the Wokwi circuit and the proven detection logic
    enclosure parametric 80 x 54 x 26 mm case
    docs assembly and test procedure
    [base.stl, lid.stl, respiguard_case.scad]
2026-08-30 Add a recordings folder and stop gitignore from swallowing WAVs
    The build and the fine-tuning happen on two different machines, so the
    hardware recordings have to travel between them, and git is the path
    already set up. The previous ignore rules excluded *.wav and data/,
    which would have let a push appear to succeed while sending nothing.
    Recordings are small — 30 s of 4 kHz mono is about 240 KB — so the
    whole set costs roughly 17 MB. The ICBHI database and the training runs
    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
2026-09-11 Fix MAX30102 sampling and breathing rate, add web simulation
    - max30102.h: FIFO config 0x4F averaged 4 samples, so data arrived at 25 Hz
    while the code assumed 100 Hz. Now 0x1F, no averaging, rollover on.
    Breathing-rate crossings use a +/-0.35 sd hysteresis band so ripple is not
    counted twice. Adds a provisional skin-contact threshold.
    - docs/index.html: browser simulation of the device (simulated data only),
    served by GitHub Pages.
    - docs/BRINGUP_GUIDE.html: correct sketch names, recorder instructions and the
    audio front-end fix to make before flashing.
    - enclosure/respiguard_blender.py: Blender render script for the case.
    [max30102.h]
